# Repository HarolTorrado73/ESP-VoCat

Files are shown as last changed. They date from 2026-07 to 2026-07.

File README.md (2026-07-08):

# ESP-VoCat Smart Rotating Base

[Español](README_ES.md) | English

> **Spanish technical documentation:** [README_ES.md](README_ES.md) · [docs/es/](docs/es/)

## Project Overview

The ESP-VoCat rotating base is a smart rotating platform designed specifically for the [**ESP-VoCat development kit**](https://docs.espressif.com/projects/esp-dev-kits/zh_CN/latest/esp32s3/esp-vocat/user_guide_v1.2.html), tailored for toys, smart speakers, smart hubs, and other products requiring large language model voice interaction capabilities. The device uses the ESP32-C61-WROOM-1 module, supports USB Type-C power supply, and can power the ESP-VoCat main unit through a magnetic interface.

This project implements **high-precision stepper motor control, magnetic slide switch event detection, CSI sensing capabilities**, and stable **UART communication** as core functions. It can automatically adjust direction based on ESP-VoCat's **Sound Source Localization** results, enabling intelligent rotation toward sound sources. By combining motion control with sound source perception, it provides a more **natural and immersive** human-computer interaction experience.

## Key Features

- **Precise Angle Control** - High-precision rotational positioning based on stepper motor
- **Magnetic Slide Switch** - Multiple sensor support with automatic calibration
- **Rich Preset Actions** - Natural movements like shake head, look around, beat rhythm
- **Auto Homing** - Automatic zero position finding and calibration on startup
- **Bidirectional Communication** - Real-time data exchange between controller and base
- **Data Persistence** - Calibration data saved, survives power loss

## Project Structure

```
esp-vocat-base/
├── hardware/                    # Hardware design files
│   ├── schematics/              # Schematics
│   └── pcb/                     # PCB design files
├── software/                    # Firmware code
│   ├── common_components/       # Shared components for all examples
│   │   ├── stepper_motor/               # Stepper motor control
│   │   ├── magnetic_slide_switch/       # Magnetic switch (profile-based)
│   │   ├── control_serial/              # Serial communication
│   │   └── BMM150_SensorAPI/            # Sensor driver
│   ├── esp_vocat_rotating_base/                         # Base firmware
│   ├── esp_vocat_rotating_base_bell_event_detection/    # Bell slider event demo
│   ├── esp_vocat_rotating_base_iphone_detection/        # iPhone detection demo
│   └── esp_vocat_rotating_base_magnetic_accessory_detection/ # Accessory detection demo
├── README_ES.md                 # Spanish documentation
└── README.md                    # English documentation (this file)
```

## Example Projects

To avoid frequent branch switching, `software/` includes 4 independently buildable example projects:

- `esp_vocat_rotating_base`  
  Base firmware with standard capabilities: stepper actions, core magnetic slider events, UART communication, calibration, and status sync.

- `esp_vocat_rotating_base_bell_event_detection`  
  Bell slider event detection demo, focused on bell-related magnetic slider event logic.

- `esp_vocat_rotating_base_iphone_detection`  
  iPhone detection demo, focused on phone approach/leave and under-base related detection events.

- `esp_vocat_rotating_base_magnetic_accessory_detection`  
  Magnetic accessory detection demo, focused on accessory magnetic event recognition (e.g. fish/ice-cream/donut style accessories).

All projects share common components under `software/common_components/`.  
The `magnetic_slide_switch` component selects different profiles per project to keep event definitions and detection behavior compatible.

## **Feature Showcase**

[**Video Showcase**](https://www.bilibili.com/video/BV19gSEBwEoj/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)

The ESP-VoCat base uses Espressif's **ESP32-C61-WROOM-1(N8R2)** module and communicates with the ESP-VoCat main unit via a custom UART protocol. In terms of mechanical structure, the base is equipped with a 24BYJ48 stepper motor, enabling sound source localization and various predefined rotation actions to enhance interaction experience.
Additionally, the ESP-VoCat base features a magnetic slide switch that unlocks more interactive experiences.

### **Sound Source Localization**
ESP-VoCat supports sound source localization, capable of real-time detection of sound direction and position in the environment. The system collects sound signals through a microphone array and analyzes sound intensity, phase, and other information to determine the azimuth of the sound source. Combined with an ultra-quiet stepper motor-based rotating base, it enables intelligent interaction facing the sound source.

Sound Source Localization

### **Multiple Preset Actions**
The rotating base supports various predefined actions:

- **Shake Head Action**
The shake head action makes the base gently swing the companion left and right, simulating a cat's curious or subtle gesture.

Shake Head

- **Curious Look Around**
The curious look around action makes the base move the companion's head left and right, with small random offsets, simulating a **cat naturally observing its environment**.

Look Around

- **Beat Rhythm**
The beat rhythm action enables ESP-VoCat to swing its head left and right according to **drum beats** in external music, creating an **interactive effect** synchronized with music.

Beat Following

- **Gentle Nuzzle**
The gentle nuzzle simulates a cat's tender nuzzling action: the base slowly turns left and returns to center, repeating several times. The motion is smooth and natural, with each pause enhancing the **tactile feel** and **gentleness**.

Nuzzle

  **Notes:**
  All actions are **parametrically controllable**, facilitating integration with large models like **Doubao** and **Xiaozhi**.
  To better execute actions, the base's motor control features:
  - **Precise Angle Control:** Supports rotation at any angle with precision up to 0.1 degrees, serving sound source localization
  - **Smooth Acceleration/Deceleration:** Uses acceleration algorithms for natural and smooth rotation
  - **Auto Homing Calibration:** 
  Since the ESP-VoCat rotating base is driven by a stepper motor, it has no angle feedback. Therefore, the base performs zero position calibration at startup:
   1. After power-on, the motor automatically rotates left to find the limit switch
   2. After touching the limit switch, the motor rotates right 95° to the center position
   3. After calibration is complete, the motor powers off

### **Magnetic Slide Switch Interaction Control**
The ESP-VoCat base implements multiple interaction controls through a **magnetic** slide switch. Different slider positions change the magnetic field strength around the magnetometer. The base identifies slider actions by monitoring these magnetic field changes in real-time. When position changes are detected, the base reports corresponding events to ESP-VoCat via serial port, enabling rich and intuitive interactive experiences.

Supports 9 types of magnetic slide switch event detection:
   - Slider moved from up to down (`SLIDE_DOWN`): Slider is moved from the upper position to the lower position.
   - Slider moved from down to up (`SLIDE_UP`): Slider is moved from the lower position to the upper position.
   - Slider removed from up position (`REMOVE_FROM_UP`): Slider is removed from the upper position.
   - Slider removed from down position (`REMOVE_FROM_DOWN`): Slider is removed from the lower position.
   - Slider placed at up position (`PLACE_FROM_UP`): Slider is placed into the upper position.
   - Slider placed at down position (`PLACE_FROM_DOWN`): Slider is placed into the lower position.
   - Single click action (`SINGLE_CLICK`): A single-click action is detected when the slider stays at the lower position.
   - Fish feeding event (`FISH_ATTACHED`): Fish accessory is detected as attached.
   - Pairing mode (`PAIRING`): Two ESP-VoCat devices are face-to-face and pairing condition is detected.

Magnetic Switch

Magnetic slide switch control supports **multiple sensors**:
 - BMM150 3-axis magnetometer
 - QMC6309 3-axis magnetometer
 - Linear Hall sensor

  **Notes:**
  1. **Choose one** of the above sensors; **BMM150** is selected by default. When using a linear Hall sensor, **only** slider up/down sliding (SLIDE_UP / SLIDE_DOWN) event detection is supported!
  2. Before first use, **fully automatic calibration** of the magnetic slide switch is required to adapt to the magnetic environment, recording magnetic field strength baseline values for three states: **up / down / removed**:
     - System automatically detects three stable positions (keep still for about 500ms each position)
     - No manual prompts required, system automatically judges position differences
     - Calibration data persistently stored via NVS Flash, survives power loss
     - During use, recalibration can be triggered by sending a serial command from ESP-VoCat or long-pressing the base's Boot button

Based on magnetometer detection results combined with intelligent motion determination algorithms, the base can recognize nine types of actions and events.

### **CSI Sensing Capability**
The companion can perceive environmental changes through Wi-Fi CSI (Channel State Information), enabling action triggering or environmental interaction.
- **Movement Detection** 
By obtaining CSI information from routers through the companion, human movement throughout the entire space can be detected, enabling human movement detection and data statistics.

- **Near-field Perception** 
Through packet exchange between the companion and base, Wi-Fi transmission paths can be controlled to achieve small-range, high-precision detection. For example, when a human finger is detected approaching, the base can automatically adjust posture or execute preset actions, enabling smarter interactive experiences.

CSI Sensing

### **Serial Communication**
The ESP-VoCat rotating base communicates with ESP-VoCat via **UART protocol**.

- **Command Types**:
    - Angle control command (CMD_BASE_ANGLE_CONTROL)
    - Preset action control command (CMD_BASE_ACTION_CONTROL)
    - Preset action completion notification (CMD_ACTION_COMPLETE)
    - Magnetic switch event report (CMD_MAGNETIC_SWITCH_EVENT)
    - Magnetic data calibration progress sync (MAG_SWITCH_CALIB_*)

Note: Currently only the above basic command types are available; CSI-related commands will be added later.
    
-  **Data Frame Format**:
    -   `AA 55 [LEN_H] [LEN_L] [CMD] [DATA...] [CHECKSUM]` 
-  **Verification Mechanism**:
    - **Frame header** verification
    - **Checksum** verification

[**Detailed command data frame example**](software/esp_vocat_rotating_base/README.md)

## **Hardware Requirements**

### **Main Control Chip**
- **ESP32-C61-WROOM-1** or **ESP32-C61-WROOM-1U** module

ESP32-C61-WROOM-1 is used by default

- [**Hardware Open Source**](https://oshwhub.com/esp-college/esp-echoear-base)

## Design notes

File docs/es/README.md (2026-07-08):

# Documentación técnica en español

Índice de la documentación del proyecto ESP-VoCat Base.

[← Guía central del proyecto](../README_ES.md)

| Documento | Descripción |
|---|---|
| [arquitectura.md](arquitectura.md) | Diagramas Mermaid: sistema, capas, UART, calibración, estados |
| [hardware.md](hardware.md) | **Hardware completo:** Main/Sub Board, análisis esquemático, GPIO, motor, sensores |
| [BOM.md](BOM.md) | **Lista de materiales** — designadores, valores, MPN, alternativas |
| [lista-compra.md](lista-compra.md) | **Lista de compra** por categorías + Espressif vs equivalentes |
| [guia-ensamblaje.md](guia-ensamblaje.md) | **Guía de fabricación** — impresión 3D, ensamblaje, calibración |
| [auditoria-hardware.md](auditoria-hardware.md) | **Auditoría hardware** — MPN, contradicciones, checklist, reproducibilidad |
| [auditoria-documentacion.md](auditoria-documentacion.md) | **Auditoría docs** — archivos chinos, plan de limpieza |
| [tablas-referencia.md](tablas-referencia.md) | GPIO, hardware, sensores, UART, eventos, proyectos |
| [arranque-firmware.md](arranque-firmware.md) | Secuencia de boot + diagramas de secuencia |
| [perfiles.md](perfiles.md) | Arquitectura `MAG_SW_PROFILE` y diferencias entre demos |
| [extender-proyecto.md](extender-proyecto.md) | Nuevo perfil, sensor, acción; buenas prácticas |
| [troubleshooting.md](troubleshooting.md) | Resolución de problemas frecuentes |

## Firmware por proyecto

- [esp_vocat_rotating_base](../software/esp_vocat_rotating_base/README_ES.md) — perfil `base`
- [bell_event_detection](../software/esp_vocat_rotating_base_bell_event_detection/README_ES.md) — perfil `bell`
- [iphone_detection](../software/esp_vocat_rotating_base_iphone_detection/README_ES.md) — perfil `iphone`
- [magnetic_accessory_detection](../software/esp_vocat_rotating_base_magnetic_accessory_detection/README_ES.md) — perfil `magnetic_accessory`

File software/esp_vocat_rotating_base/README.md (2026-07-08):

# ESP-VoCat Rotating Base

[Español](README_ES.md) | **English**

## Project Introduction

This project is the firmware for the rotating base of Espressif's ESP-VoCat intelligent interactive device, developed based on the ESP32-C61 chip. The project implements precise stepper motor control, magnetic slide switch detection, UART communication, and other features, providing vivid interactive actions and sensitive input detection for smart devices.

## Main Features

### Stepper Motor Control
- **Multiple Predefined Actions**:
  - Head shaking action (fixed amplitude/gradual decay)
  - Look around observation action
  - Cat nuzzle action
  - Beat swing action following rhythm

All actions are parameterizable for easy integration with LLMs like Doubao and Xiaozhi.
- **Precise Angle Control**: Supports arbitrary angle rotation with precision up to 0.1 degrees
- **Smooth Acceleration/Deceleration**: Uses acceleration/deceleration algorithms for more natural and fluid motion
- **Half-Step Drive Mode**: Doubles precision for smoother movement
- **Auto Homing Calibration**: Automatically returns to zero position via limit switch on startup

### Magnetic Slide Switch
- **Multiple Sensor Support**:
  - BMM150 3-axis magnetometer
  - QMC6309 3-axis magnetometer
  - Linear Hall sensor

Choose one of the above three sensors, BMM150 is selected by default.
- **Rich Event Detection**:
  - Slider up/down sliding (SLIDE_UP / SLIDE_DOWN)
  - Remove from up/down position (REMOVE_FROM_UP / REMOVE_FROM_DOWN)
  - Place back from up/down position (PLACE_FROM_UP / PLACE_FROM_DOWN)
  - Single click event (SINGLE_CLICK): Detected based on mag_x axis data changes, combined with mag_x and mag_y relationship judgment to prevent false triggers from sliding
  - Fish feeding event (FISH_ATTACHED): Detects specific magnetic field changes when small fish is placed from up position
  - Pairing mode (PAIRING): Two ESP-VoCat devices face-to-face for pairing and networking
- **Smart Calibration Function**:
  - Fully automatic calibration process: No manual prompts required, system automatically detects three stable positions
  - Fast stability detection: 500ms stability time for both BMM150 and QMC6309
  - Intelligent position recognition: Automatically judges position differences to avoid duplicate recording
  - Calibration data persistent storage (NVS Flash)
  - Support UART command triggered recalibration
  - Support long press Boot button triggered recalibration
  - Auto-adapt to different magnetic field environments

### UART Communication
- **UART Protocol Communication**: Data communication with ESP-VoCat
- **Command Types**:
  - Angle control command (CMD_BASE_ANGLE_CONTROL)
  - Preset action control command (CMD_BASE_ACTION_CONTROL)
  - Preset action completion notification (CMD_ACTION_COMPLETE)
  - Magnetic switch event reporting (CMD_MAGNETIC_SWITCH_EVENT)
  - Calibration progress notification (MAG_SWITCH_CALIB_*)
- **Data Frame Format**: `AA 55 [LEN_H] [LEN_L] [CMD] [DATA...] [CHECKSUM]`
- **Verification Mechanism**: Supports **frame header** verification and **checksum** validation

## Hardware Requirements

### Main Control Chip
- **ESP32-C61-WROOM-1** or **ESP32-C61-WROOM-1U** module

ESP32-C61-WROOM-1 is used by default

### Peripheral Connection and Pin Assignment

#### Stepper Motor (28BYJ-48 + ULN2003 Driver IC)
- IN1 → GPIO28
- IN2 → GPIO27
- IN3 → GPIO26
- IN4 → GPIO25

#### Magnetometer Sensor (I2C)
- SCL → GPIO3
- SDA → GPIO2
- Supports BMM150 (I2C address: 0x10)
- Supports QMC6309 (I2C address: 0x7C)

#### Linear Hall Sensor (ADC)
- ADC_PIN → GPIO5 (ADC_CHANNEL_3)

#### Turntable Homing Calibration Limit Switch
- Homing calibration limit switch detection pin → GPIO1 (active low)

#### BOOT Button
- BOOT button → GPIO9 (active low)

Used by default for long press to trigger magnetic slide switch calibration.

#### UART Communication
- TXD → GPIO29
- RXD → GPIO8
- Baud rate: 115200

## Software Architecture

### Main Components

#### 1. stepper_motor (Stepper Motor Control)
- Implements half-step drive control algorithm
- Provides acceleration/deceleration curves
- Encapsulates multiple predefined actions
- Supports precise angle rotation

#### 2. magnetic_slide_switch (Magnetic Slide Switch)
- Sliding window filtering algorithm (mag_z axis)
- State machine implements event detection
- Single click detection (based on mag_x axis change + mag_x/mag_y relationship judgment)
- Fish feeding event detection (specific magnetic field increment range)
- Pairing mode detection (two ESP-VoCat face-to-face for pairing)
- Fully automatic calibration process (time-based + intelligent position recognition)
- Calibration data NVS persistent storage

#### 3. control_serial (UART Communication)
- UART TX/RX tasks
- Protocol frame parsing
- Command dispatch processing
- Event reporting

#### 4. BMM150_SensorAPI (Sensor Driver)
- BMM150 official API adaptation
- I2C bus encapsulation

### Task Structure
```
app_main
├── base_calibration_task          // Base angle calibration task (on startup)
├── uart_cmd_receive_task          // UART command receive task
├── uart_cmd_send_task             // UART command send task
├── magnetometer_data_read_task    // Magnetometer data read task (shared data source)
├── magnetometer_calibration_task  // Magnetic switch automatic calibration task
└── slide_switch_event_detect_task // Magnetic slide switch event detection task
```

## Quick Start

### Environment Preparation

1. **ESP-IDF Version**

- ESP-IDF release/v5.5(v5.5-445-g1191f4c4f91-dirty)

### Project Configuration

Use `idf.py menuconfig` to select the sensor for the magnetic slide switch:

 `Component config → Magnetic Slide Switch → Sensor Type`

Select sensor type: BMM150 / QMC6309 / Linear Hall Sensor

### Build and Flash

```bash
# Build project
idf.py build
# Flash firmware
idf.py flash
# View logs
idf.py monitor
```

## Usage Instructions

### First Startup

1. **Base Angle Calibration**:
   - After power-on, the motor will automatically rotate left to find the limit switch
   - After touching the limit switch, the motor will rotate right 95° to the center position
   - After calibration is complete, the motor powers off

2. **Magnetic Switch Automatic Calibration** (if first use):
   - System automatically detects the first stable position (keep slider still for about 500ms)
   - After the system records the first position, prompt: `First position calibrated`
   - Move the slider to a second different position (up/down/removed), system automatically detects stability
   - After the system records the second position, send `0x12` to ESP-VoCat to notify second position calibration complete
   - Move the slider to a third different position, system automatically detects stability
   - After the system records the third position, automatically sort by magnetic field strength and assign to REMOVED/UP/DOWN
   - After calibration is complete, send `0x13` to ESP-VoCat to notify calibration complete
   - Calibration data is automatically saved to Flash, automatically loaded on next startup
   
   **Note**:
   - Each position needs to be kept still for system to automatically detect stability (about 500ms)
   - The magnetic field difference between three positions must be greater than 100 (system automatically judges)
   - Data changes during movement are normal, system will automatically wait for stability before recording

### Recalibration

**Method 1: Long Press Boot Button**
- Long press the Boot button on GPIO9 (about 1.5 seconds)
- System automatically enters recalibration mode

**Method 2: UART Command**
- Send command: `AA 55 00 03 03 00 10 16`
- System enters recalibration mode after receiving the command

### UART Commands

#### 1. Magnetic Attachment Notification Command（0x00）
`
AA 55 00 03 00 00 01 01
`

The base periodically sends this command. Once ESP-VoCat is magnetically attached and successfully receives the command, it can confirm that the connection to the base has been established and then start playing the connection animation.

#### 2. Angle Control Command (0x01)
**Format**: `AA 55 00 03 01 [ANGLE_H] [ANGLE_L] [CHECKSUM]`

**Example**: Rotate to 45°
```
AA 55 00 03 01 00 2D 2E
```
- `00 2D` = 45 (decimal)
- `2E` = `01 + 00 + 2D` (checksum)

#### 3. Action Control Command (0x02)
**Format**: `AA 55 00 03 02 00 [ACTION] [CHECKSUM]`

**Action Codes**:
- `0x01`: Shake head (SHAKE_HEAD)
- `0x02`: Look around (LOOK_AROUND)
- `0x03`: Beat swing - drum (BEAT_SWING_DRUM)
- `0x04`: Cat nuzzle (CAT_NUZZLE)
- `0x05`: Beat swing - other instruments (BEAT_SWING_OTHER)

**Example**: Execute look around action
```
AA 55 00 03 02 00 02 04
```

#### 4. Magnetic Switch Event Reporting (0x03)
**Format**: `AA 55 00 03 03 00 [EVENT] [CHECKSUM]`

**Event Codes**:
- `0x01`: Slider slides down (SLIDE_DOWN)
- `0x02`: Slider slides up (SLIDE_UP)
- `0x03`: Remove from top (REMOVE_FROM_UP)
- `0x04`: Remove from bottom (REMOVE_FROM_DOWN)
- `0x05`: Place back from top (PLACE_FROM_UP)
- `0x06`: Place back from bottom (PLACE_FROM_DOWN)
- `0x07`: Single click event (SINGLE_CLICK)
- `0x08`: Fish feeding event (FISH_ATTACHED) - Triggered when small fish is placed from up position
- `0x09`: Pairing mode (PAIRING) - Two ESP-VoCat face-to-face for pairing
- `0x10`: Start calibration program
- `0x11`: Calibration start notification
- `0x12`: Second position calibration complete (ESP-VoCat gives voice prompt for third step after receiving)
- `0x13`: Calibration complete

#### 5. Action Completion Notification (0x02)
**Format**: `AA 55 00 03 02 00 10 12`

- Base automatically sends after completing any specific action
- ESP-VoCat can synchronize status according to this command

## Stepper Motor Action Details

### 1. stepper_shake_head (Shake Head)
```c
stepper_shake_head(float amplitude, int cycles, int speed_us);
```
- `amplitude`: Swing amplitude (degrees)
- `cycles`: Number of swings
- `speed_us`: Speed (microseconds/step)

### 2. stepper_shake_head_decay (Gradual Decay Shake Head)
```c
stepper_shake_head_decay(float initial_amplitude, float decay_rate, int speed_us);
```
- `initial_amplitude`: Initial amplitude (degrees)
- `decay_rate`: Decay coefficient (0.0-1.0, e.g., 0.8 means 20% decay each time)
- `speed_us`: Speed (microseconds/step)

### 3. stepper_look_around (Look Around)
```c
stepper_look_around(float left_angle, float right_angle, float scan_angle, 
                    int pause_ms, int large_speed_us, int small_speed_us);
```
- `left_angle`: Maximum left angle
- `right_angle`: Maximum right angle
- `scan_angle`: Small amplitude scan angle
- `pause_ms`: Pause time after each rotation
- `large_speed_us`: Large amplitude rotation speed
- `small_speed_us`: Small amplitude scan speed

### 4. stepper_cat_nuzzle (Cat Nuzzle)
```c
stepper_cat_nuzzle(float angle, int cycles, int speed_us);
```
- `angle`: Nuzzle amplitude (degrees)
- `cycles`: Number of nuzzles
- `speed_us`: Speed (microseconds/step)

### 5. stepper_beat_swing (Beat Swing)
```c
stepper_beat_swing(float angle, int speed_us);
```
- `angle`: Swing angle (degrees)
- `speed_us`: Speed (microseconds/step)
- **Smart Swing Logic**:
  - Same instrument type continuously triggered → Swing 15 degrees to the other side

## Magnetic Switch Calibration Principle

### Automatic Calibration Flow State Machine

```
CALIBRATION_DETECTING_FIRST      // Automatically detect first stable position
         ↓                       // Record automatically after data stable for 500ms
CALIBRATION_WAITING_CHANGE_1     // Wait for data change (user moves slider)
         ↓                       // Change amount detected > 100
CALIBRATION_DETECTING_SECOND     // Automatically detect second stable position
         ↓                       // Record automatically after data stable for 500ms
         |                       // (Send 0x12 to notify ESP-VoCat)
CALIBRATION_WAITING_CHANGE_2     // Wait for data change (user moves slider)
         ↓                       // Change amount detected > 100
CALIBRATION_DETECTING_THIRD      // Automatically detect third stable position
         ↓                       // Record automatically after data stable for 500ms
CALIBRATION_COMPLETED            // Auto sort and save to Flash
                                 // (Send 0x13 to notify ESP-VoCat)
```

### Key Technical Points

1. **Sliding Window Filtering**: 5-point moving average to reduce noise interference
2. **Time-based Stability Detection**:
   - Uses system clock (FreeRTOS Tick) for precise timing
   - Data change less than 10 units considered stable
   - Both BMM150 and QMC6309: Record after continuous stability for 500ms
3. **Intelligent Position Recognition**:
   - Automatically detects data change amount (threshold 100)
   - New position must be significantly different from recorded positions
   - Prevents duplicate recording of same position
4. **Automatic Sorting and Assignment**:
   - Sort by magnetic field strength from small to large
   - Smallest value → REMOVED (removed)
   - Middle value → UP (up position)
   - Largest value → DOWN (down position)
5. **NVS Persistence**: Calibration data saved to Flash, not lost after power off
6. **No Manual Prompts Required**: Fully automatic detection, users only need to move slider in sequence and keep still

### Magnetic Field Value Reference Range (BMM150)
- **REMOVED** (removed): ~700-800 (default 709)
- **UP** (up position): ~1300-1400 (default 1383)
- **DOWN** (down position): ~2000-2100 (default 2047)
- **FISH_ATTACHED** (fish feeding): REMOVED + 150~200

*Note: Actual values vary due to magnet strength and installation position, automatic calibration will assign positions based on actual magnetic field*

### Event Detection Features

**Single Click Event Detection**:
- Based on mag_x axis data change (drop/rise threshold: 100)
- Combined with mag_x and mag_y size relationship to judge slider position
- Only detected when slider is at DOWN position (mag_x > mag_y)
- Duration filtering: < 300ms for valid click
- Prevents false triggers from fast sliding

**Fish Feeding Event Detection**:
- Only detected after REMOVED position
- Magnetic field increment in 150-200 range
- Distinguished from PLACE_FROM_UP (larger increment, close to UP_CENTER)

**Pairing Mode Detection**:
- Magnetic field continues to drop after REMOVED position
- Drop amount > 100 (BMM150) / 150 (QMC6309)
- Stably maintains this state

### Common Issues

**Q1: Motor vibrates or doesn't rotate**
- Check if power supply is sufficient (at least 5V 1A)
- Check if wiring is correct
- Try reducing speed (increase `speed_us` parameter)

**Q2: Magnetic switch calibration fails**
- Ensure sensor I2C connection is normal
- Check if sensor type configuration matches
- Each position needs to be kept still for at least 500ms (both BMM150 and QMC6309)
- The magnetic field difference between three positions must be greater than 100, ensure positions are clearly different
- If movement is too fast causing detection failure, wait a moment for system to re-detect

**Q3: Single click event false trigger or not triggered**
- False trigger: May be caused by fast sliding, system has been optimized through mag_x/mag_y relationship
- Not triggered: Ensure slider is at DOWN position (mag_x > mag_y), click action should be clear and fast
- Click duration should be less than 300ms, too slow will be recognized as sliding

**Q4: UART communication abnormal**
- Check if baud rate is 115200
- Confirm TX/RX wiring is correct
- Check if checksum is calculated correctly

**Q5: Motor rotates in wrong direction on first power-on**
- Check limit switch installation position
- Adjust rotation angle in `base_calibration_task`

## Performance Parameters

- **Angle Control Precision**: ±0.5°
- **Fastest Rotation Speed**: 600 μs/step (about 200°/second)
- **Magnetic Switch Response Time**: < 50ms
- **Magnetic Switch Sampling Rate**: 100 Hz (BMM150, 10ms period) / 500 Hz (QMC6309, 2ms period)
- **Calibration Stability Detection Time**: 500ms (both BMM150 and QMC6309)
- **Single Click Detection Time Window**: < 300ms (BMM150) / < 250ms (QMC6309)
- **UART Communication Rate**: 115200 bps
- **Memory Usage**: ~80KB RAM, ~200KB Flash

## Version History

### v1.1.0
- **New Features**:
  - Fish feeding event detection (FISH_ATTACHED)
  - Pairing mode detection (PAIRING)
- **Optimizations**:
  - Fully automatic magnetic data calibration process (no manual prompts required)
  - Time-based stability detection (FreeRTOS Tick timing)
  - Single click event detection optimization: Based on mag_x axis + mag_x/mag_y relationship judgment
  - Prevents false single click triggers from fast sliding
  - Calibration stability time optimization: Both BMM150 and QMC6309 reduced to 500ms
  - Intelligent position recognition (automatically judges position differences)

### v1.0.0
- Stepper motor basic control
- Multiple predefined actions
- Magnetic slide switch event detection
- Auto calibration function
- NVS data persistence
- UART communication protocol
- Smart beat following algorithm
- Long press Boot button recalibration
- Calibration process UART communication

## License

This project follows the GPL 3.0 license.

---

**Note**: This project is supporting firmware for Espressif's ESP-VoCat smart device, for learning and reference only.

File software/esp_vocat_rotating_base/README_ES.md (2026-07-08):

# ESP-VoCat Base: Firmware estándar

**[Español](README_ES.md)** | [English](README.md)

> **Perfil:** `base` · **Versión:** V1.0.4  
> **Documentación completa:** [Guía central del proyecto](../../README_ES.md)

---

## Descripción

Firmware principal de la base rotatoria ESP-VoCat. Implementa control del motor paso a paso, detección magnética con perfil `base`, comunicación UART y calibración automática.

**Diferencia clave respecto a los demos:** en este proyecto los eventos magnéticos se envían por UART **directamente** desde `magnetic_slide_switch.c` (sin callback en `app_main`).

---

## Eventos soportados (perfil `base`)

| Código | Evento |
|---|---|
| 1–7 | Deslizamiento, colocación, retirada, clic simple |
| 8–9 | Pez adherido / retirado |
| 10–11 | Emparejamiento / cancelado |

Tabla completa: [Tablas de referencia → Eventos](../../docs/es/tablas-referencia.md#perfil-base-esp_vocat_rotating_base)

---

## Compilar

```bash
cd software/esp_vocat_rotating_base
idf.py set-target esp32c61
idf.py menuconfig    # Magnetic Slide Switch → Sensor Type
idf.py build flash monitor
```

---

## Documentación relacionada

| Tema | Enlace |
|---|---|
| GPIO, UART, acciones | [Tablas de referencia](../../docs/es/tablas-referencia.md) |
| Arranque y secuencias | [Arranque del firmware](../../docs/es/arranque-firmware.md) |
| Arquitectura | [Arquitectura del sistema](../../docs/es/arquitectura.md) |
| Comandos UART detallados | [Tablas → UART](../../docs/es/tablas-referencia.md#comandos-uart) |
| Calibración magnética | [Arquitectura → Calibración](../../docs/es/arquitectura.md#5-flujo-de-calibración-automática-magnética) |
| Problemas frecuentes | [Troubleshooting](../../docs/es/troubleshooting.md) |

---

## Tareas FreeRTOS de esta aplicación

```
app_main
├── base_calibration_task          # Homing mecánico (GPIO 1 → +95°)
├── uart_cmd_receive_task          # Comandos UART (prioridad 12)
├── magnetic_detect_task           # Acoplamiento magnético cada 500 ms
├── mag_data_read_task             # Lectura sensor I2C
├── mag_calibration_task           # Calibración automática 3 posiciones
└── slide_switch_event_detect_task # Detección de eventos → UART directo
```

---

## Licencia

GPL-3.0 — Firmware de referencia para el kit ESP-VoCat de Espressif.

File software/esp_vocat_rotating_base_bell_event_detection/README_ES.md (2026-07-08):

# ESP-VoCat Base: Detección de eventos de campana

**[Español](README_ES.md)** | [English](README.md)

> **Perfil:** `bell` · **Versión:** V1.0.4  
> **Documentación completa:** [Guía central del proyecto](../../README_ES.md)

---

## Descripción

Demostración centrada en el **deslizador tipo campana**. Utiliza el perfil `magnetic_slide_switch/profiles/bell` y registra un callback en `app_main` que reenvía los eventos detectados a ESP-VoCat por UART.

```c
// esp_vocat_rotating_base_main.c
magnetic_slide_switch_register_callback(magnetic_slide_switch_event_cb);
```

---

## Eventos soportados (perfil `bell`)

| Código | Evento |
|---|---|
| 1 | `SLIDE_DOWN` |
| 2 | `SLIDE_UP` |
| 3 | `REMOVE_FROM_UP` |
| 4 | `REMOVE_FROM_DOWN` |
| 5 | `PLACE_FROM_UP` |
| 6 | `PLACE_FROM_DOWN` |
| 7 | `SINGLE_CLICK` |

No incluye eventos de pez, emparejamiento, iPhone ni accesorios.

Detalle: [Sensado magnético → Campana](../../magnetic_sensing_interaction_solution_es.md#21-demostración-de-eventos-del-deslizador-tipo-campana)

---

## Compilar

```bash
cd software/esp_vocat_rotating_base_bell_event_detection
idf.py set-target esp32c61
idf.py build flash monitor
```

`CMakeLists.txt` define `set(MAG_SW_PROFILE "bell")`.

---

## Diferencias respecto al firmware base

| Aspecto | `base` | `bell` (este proyecto) |
|---|---|---|
| Perfil CMake | `base` | `bell` |
| Eventos | 1–11 | 1–7 |
| Reporte UART | Directo en componente | Callback en `app_main` |
| Pez / emparejamiento | Sí | No |

Comparativa completa: [Perfiles](../../docs/es/perfiles.md#diferencias-entre-perfiles)

---

## Documentación relacionada

| Tema | Enlace |
|---|---|
| Arquitectura de perfiles | [docs/es/perfiles.md](../../docs/es/perfiles.md) |
| Tablas GPIO / UART | [docs/es/tablas-referencia.md](../../docs/es/tablas-referencia.md) |
| Troubleshooting | [docs/es/troubleshooting.md](../../docs/es/troubleshooting.md) |

---

## Licencia

GPL-3.0

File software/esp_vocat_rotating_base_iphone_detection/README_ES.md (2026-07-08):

# ESP-VoCat Base: Detección de iPhone

**[Español](README_ES.md)** | [English](README.md)

> **Perfil:** `iphone` · **Versión:** V1.0.4  
> **Documentación completa:** [Guía central del proyecto](../../README_ES.md)

---

## Descripción

Demostración de **detección de proximidad de iPhone** mediante variaciones del eje Z del magnetómetro respecto a la línea base calibrada. Usa el perfil `magnetic_slide_switch/profiles/iphone`.

Los eventos se reportan vía callback registrado en `app_main` → `control_serial_send_magnetic_switch_event()`.

---

## Eventos soportados (perfil `iphone`)

| Código | Evento | Criterio (BMM150) |
|---|---|---|
| 16 | `IPHONE_LEAN_FRONT` | ΔZ ≥ 450 respecto a baseline |
| 17 | `IPHONE_LEAN_FRONT_DETACHED` | iPhone se separa del frente |
| 18 | `IPHONE_UNDER_BASE` | Caída de Z ≥ 600 (bajo la base) |
| 19 | `IPHONE_UNDER_BASE_DETACHED` | iPhone retirado de debajo |

Umbrales definidos en `profiles/iphone/include/magnetic_slide_switch.h` (`MAGNETIC_ACCESSORY_DETECTION_Z_INCREASE`, `MAGNETIC_ACCESSORY_DETECTION_Z_DROP_UNDER_BASE`).

Detalle: [Sensado magnético → iPhone](../../magnetic_sensing_interaction_solution_es.md#22-demostración-de-detección-de-iphone)

---

## Compilar

```bash
cd software/esp_vocat_rotating_base_iphone_detection
idf.py set-target esp32c61
idf.py build flash monitor
```

`CMakeLists.txt` define `set(MAG_SW_PROFILE "iphone")`.

---

## Diferencias respecto al firmware base

| Aspecto | `base` | `iphone` (este proyecto) |
|---|---|---|
| Eventos de deslizador | Sí (1–7) | No |
| Eventos iPhone | No | Sí (16–19) |
| Lógica de detección | Eje Z + estados UP/DOWN | Variación ΔZ vs baseline |

---

## Documentación relacionada

| Tema | Enlace |
|---|---|
| Perfiles | [docs/es/perfiles.md](../../docs/es/perfiles.md) |
| Calibración | [docs/es/arranque-firmware.md](../../docs/es/arranque-firmware.md) |
| Troubleshooting | [docs/es/troubleshooting.md](../../docs/es/troubleshooting.md) |

---

## Licencia

GPL-3.0

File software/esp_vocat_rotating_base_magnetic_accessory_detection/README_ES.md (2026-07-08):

# ESP-VoCat Base: Detección de accesorios magnéticos

**[Español](README_ES.md)** | [English](README.md)

> **Perfil:** `magnetic_accessory` · **Versión:** V1.0.4  
> **Documentación completa:** [Guía central del proyecto](../../README_ES.md)

---

## Descripción

Demostración de **accesorios magnéticos** (pez, helado, dona) y modo emparejamiento. Usa el perfil `magnetic_slide_switch/profiles/magnetic_accessory` con detección basada en incrementos del eje Z respecto a la posición `REMOVED` calibrada.

Incluye **baseline dinámico** (EMA) y **confirmación retardada** (`ACCESSORY_CONFIRM_MS = 200 ms`) para distinguir accesorios.

---

## Eventos soportados (perfil `magnetic_accessory`)

| Código | Evento |
|---|---|
| 8 | `FISH_ATTACHED` |
| 9 | `FISH_DETACHED` |
| 10 | `PAIRING` |
| 11 | `PAIRING_CANCELLED` |
| 12 | `ICE_CREAM_ATTACHED` |
| 13 | `ICE_CREAM_DETACHED` |
| 14 | `DONUT_ATTACHED` |
| 15 | `DONUT_DETACHED` |

### Rangos ΔZ (BMM150, desde `magnetic_slide_switch.h`)

| Accesorio | ΔZ mínimo | ΔZ máximo |
|---|---|---|
| Pez | 50 | 130 |
| Helado | 140 | 200 |
| Dona | 270 | 310 |

Detalle: [Sensado magnético → Accesorios](../../magnetic_sensing_interaction_solution_es.md#23-demostración-de-detección-de-accesorios-magnéticos)

---

## Compilar

```bash
cd software/esp_vocat_rotating_base_magnetic_accessory_detection
idf.py set-target esp32c61
idf.py build flash monitor
```

`CMakeLists.txt` define `set(MAG_SW_PROFILE "magnetic_accessory")`.

---

## Diferencias respecto al firmware base

| Aspecto | `base` | `magnetic_accessory` |
|---|---|---|
| Detección pez | Por deslizador (campo total) | Por ΔZ en posición REMOVED |
| Helado / dona | No | Sí |
| Baseline dinámico | No | Sí (`DYNAMIC_BASELINE_EMA_SHIFT`) |
| Confirmación retardada | No | Sí (200 ms) |

---

## Documentación relacionada

| Tema | Enlace |
|---|---|
| Perfiles y extensión | [docs/es/perfiles.md](../../docs/es/perfiles.md) |
| Tablas de eventos | [docs/es/tablas-referencia.md](../../docs/es/tablas-referencia.md) |
| Troubleshooting calibración | [docs/es/troubleshooting.md#2-el-sensor-no-calibra](../../docs/es/troubleshooting.md#2-el-sensor-no-calibra) |

---

## Licencia

GPL-3.0

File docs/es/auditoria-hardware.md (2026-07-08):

# Auditoría final de hardware — ESP-VoCat Base V1.0

> **Fecha de auditoría:** 2026-07-08  
> **Alcance:** contrastar esquemáticos PDF (`hardware/`), exportación OSHWHUB (`docs/7726, 2155.txt`), página web OSHWHUB, firmware (`software/`) y documentación de fabricación (`docs/es/`).  
> **Regla:** no se han inventado MPN ni valores no presentes en las fuentes.

[← BOM](BOM.md) · [Lista de compra](lista-compra.md) · [Guía de ensamblaje](guia-ensamblaje.md) · [Hardware](hardware.md)

---

## 1. Fuentes consultadas

| Fuente | Contenido útil | Limitaciones |
|---|---|---|
| `hardware/SCH_*MainBoard*.pdf` | Valores R/C/L, referencias IC, huellas conectoras | PDF no exporta MPN de diodos, LED ni inductor |
| `hardware/SCH_*SubBoard*.pdf` | TM-8764-1, R1/R2, pogo, CN1 | Sin MPN pogo pin |
| `docs/7726, 2155.txt` | BOM parcial (5 líneas pasivos), montaje, mecánica | Exportación web incompleta; BOM truncada |
| [OSHWHUB esp-echoear-base](https://oshwhub.com/esp-college/esp-echoear-base) (web, 2026-07-08) | Montaje, GPIO, espesor PCB, pogo orientación | Pestaña **BOM: «暂无BOM»** (sin BOM publicada) |
| `3D_models/*.stp` | Geometría 5 piezas | Sin material, orientación, relleno |
| `software/` | GPIO, homing 95°, perfil sensores | No sustituye BOM de componentes |

---

## 2. Diagrama de alimentación

```mermaid
flowchart TB
    subgraph ENTRADA["Entrada"]
        USBC["USB1<br/>TYPE-C 16PIN 2MD(073)<br/>VBUS 5 V"]
        CC["R1, R4 — 5,1 kΩ<br/>líneas CC"]
        D_USB["D1–D3<br/>MPN: no disponible en repo"]
    end

    subgraph PROTECCION["Protección / distribución 5 V"]
        D_VBUS["D6–D7<br/>MPN: no disponible en repo"]
        TPS["U3 TPS2051BDBVR<br/>límite 500 mA"]
        VBUS_RAW["VBUS 5 V<br/>motor + periféricos"]
        VBUS_OUT["VBUS_OUT<br/>→ pogo pin → host ESP-VoCat"]
    end

    subgraph REG["Regulador 3,3 V"]
        DCDC["U2 TLV62569DBVR"]
        L1["L1 — 2,2 µH<br/>MPN: requiere OSHWHUB"]
        C_BUCK["C1,C2,C7,C8<br/>10 µF / 100 nF / 22 µF"]
        V33["VCC_3V3"]
    end

    subgraph MCU["ESP32 y lógica"]
        U1["U1 ESP32-C61-WROOM-1"]
        BOOT_SW["BOOT GT-TC072A-H060-L1"]
        LED["LED1 + R8,R9 4,7 kΩ<br/>tipo LED: no disponible"]
    end

    subgraph MOTOR["Motor 5 V"]
        ULN["U4 ULN2003A"]
        M1["M1 24BYJ48<br/>5 V DC"]
        CN1["CN1 1,25-5P"]
    end

    subgraph SENSORES["Sensores 3,3 V"]
        MAG["U5 BMM150<br/>o U6 QMC6309"]
        HALL["U7 SS49E + C14,C15"]
        I2C_HDR["CN2 I2C expansión"]
    end

  subgraph SUB["Sub Board vía FFC"]
        POGO["U1 pogo 4P 2,5 mm"]
        LSW["SW1 TM-8764-1"]
    end

    USBC --> CC
    USBC --> D_USB
    USBC --> D_VBUS
    USBC --> TPS
    USBC --> VBUS_RAW
    TPS --> VBUS_OUT
    VBUS_OUT --> POGO
    VBUS_RAW --> DCDC
    VBUS_RAW --> ULN
    DCDC --> L1 --> V33
    C_BUCK --> V33
    V33 --> U1
    V33 --> MAG
    V33 --> HALL
    V33 --> I2C_HDR
    BOOT_SW --> U1
    LED --> U1
    U1 --> ULN --> CN1 --> M1
    U1 --> MAG
    U1 --> HALL
    CN3["CN3 SH1.0 5P"] --> LSW
    CN3 --> POGO
    VBUS_OUT -.-> CN3
```

**Ramas de tensión confirmadas:**

| Rail | Origen | Consumidores principales |
|---|---|---|
| **VBUS 5 V** | USB Type-C | TLV62569 (entrada), ULN2003A/motor, TPS2051B (entrada), expansión VBUS |
| **VCC_3V3** | TLV62569 + L1 2,2 µH | ESP32-C61, BMM150/QMC6309, SS49E, lógica |
| **VBUS_OUT** | TPS2051B (≤500 mA) | Host ESP-VoCat vía pogo pin |

---

## 3. Verificación R/C — esquemático vs BOM vs lista de compra

### 3.1 Condensadores (Main Board)

| Designadores | Valor (esquemático) | BOM.md | lista-compra.md | OSHWHUB | Estado |
|---|---|---|---|---|---|
| C1, C3, C8 | 10 µF | 10 µF ×3, C0603, CL10A106K | 3 × 10 µF | ID 1, CL10A106K | **Coincide** |
| C2, C4, C5, C6, C10–C14 | 100 nF | 100 nF ×9 | ~~10~~ → **9** × 100 nF (corregido) | ID 2, CL05B104K ×9 | **Coincide** (error previo en lista-compra: decía 10) |
| C9 | 1 µF | 1 µF | 1 × 1 µF | ID 3, CL05A105K | **Coincide** |
| C7 | 22 µF | 22 µF | 1 × 22 µF | No en export. parcial | **Valor coincide**; huella/MPN: no disponible |
| C15 | 10 nF | 10 nF | 1 × 10 nF | No en export. parcial | **Valor coincide**; huella/MPN: no disponible |

### 3.2 Resistencias (Main Board)

| Designadores | Valor (esquemático) | BOM.md | lista-compra.md | OSHWHUB | Estado |
|---|---|---|---|---|---|
| R1, R4 | 5,1 kΩ | 5,1 kΩ ×2 | 2 × 5,1 kΩ | No en export. | **Coincide** |
| R2 | 100 kΩ | 100 kΩ | 1 × 100 kΩ | No en export. | **Coincide** |
| R3, R6 | 10 kΩ | 10 kΩ ×2 | (incl. en 4×10 kΩ) | ID 4 parcial | **Coincide** |
| R5 | 22,1 kΩ | 22,1 kΩ | 1 × 22,1 kΩ | No en export. | **Coincide** |
| R7 | 1 kΩ | 1 kΩ | 1 × 1 kΩ | No en export. | **Coincide** |
| R8, R9 | 4,7 kΩ | 4,7 kΩ ×2 | 2 × 4,7 kΩ | ID 5 parcial | **Coincide** |
| R10, R11 | 10 kΩ | 10 kΩ ×2 | (incl. en 4×10 kΩ) | ID 4 parcial | **Coincide** |

### 3.3 Resistencias (Sub Board)

| Designadores | Valor | BOM / lista-compra | Esquemático | Estado |
|---|---|---|---|---|
| R1 | 51 kΩ | 51 kΩ | 51 kΩ | **Coincide** |
| R2 | 100 kΩ | 100 kΩ | 100 kΩ | **Coincide** |

### 3.4 Inductor

| Designador | Valor esquemático | BOM | lista-compra | MPN |
|---|---|-----|---|-----|
| L1 | 2,2 µH | Confirmado | Pendiente | **Requiere consultar OSHWHUB** (proyecto clonado en EasyEDA) |

---

## 4. Búsqueda de MPN faltantes

### 4.1 Resultado por componente

| Ref. | Tipo | Dato en esquemático PDF | Dato en OSHWHUB repo/web | MPN identificado | Conclusión |
|---|---|---|---|---|---|
| **D1–D3** | Diodos USB | Designadores junto a USB_DP/DN | Sin mención | — | **No disponible en el repositorio.** Requiere clonar proyecto EasyEDA en OSHWHUB |
| **D4–D5** | Diodos Boot | Designadores en circuito BOOT | Sin mención | — | **No disponible en el repositorio** |
| **D6–D7** | Diodos VBUS | Designadores en rama VBUS | Sin mención | — | **No disponible en el repositorio** |
| **LED1** | LED | Designador + R8/R9 4,7 kΩ | Sin mención | — | **No disponible en el repositorio** (color, encapsulado, corriente) |
| **L1** | Inductor | **2,2 µH** | Sin mención | — | Valor confirmado; **MPN y encapsulado: requiere OSHWHUB** |
| **USB1** | USB Type-C | Huella `TYPE-C 16PIN 2MD(073)` | Sin MPN | — | **Referencia de biblioteca EasyEDA**, no MPN LCSC en repo |
| **CN1** | Motor | `1.25-5P WT` | Sin MPN | — | **Referencia de huella**; requiere OSHWHUB |
| **CN2** | I2C | `HC-1.25-4PLT` | Sin MPN | — | **Referencia de huella** |
| **CN3 / CN1 Sub** | FFC | `WAFER-SHB1.0-5PLT-W1-P` | Cable SH1.0 5P 60 mm | — | Especificación mecánica confirmada; **MPN conector: requiere OSHWHUB** |
| **CN4** | RGB | `HC-1.25-3PLT` | Sin MPN | — | **Referencia de huella** |
| **H1** | LD2402 | `PZ254V-11-05P` | LD2402 listado | — | Header genérico 2,54 mm 5P; **MPN exacto: requiere OSHWHUB** |
| **U1 Sub** | Pogo pin | 4P 2,5 mm (silk) | «conector macho 4 pines 2,5 mm con oreja» | — | Especificación mecánica confirmada; **MPN: requiere OSHWHUB** |
| **SW1** | Fin de carrera | **TM-8764-1** | Sin MPN adicional | TM-8764-1 | **Referencia de componente EasyEDA** confirmada en esquemático; MPN fabricante/LCSC no verificado en repo |
| **BOOT** | Táctil | **GT-TC072A-H060-L1** | Sin MPN | GT-TC072A-H060-L1 | **Confirmado** (texto en esquemático) |
| **Rodamiento** | Mecánico | — | 7×11×3 mm | — | Dimensiones confirmadas; **MPN: requiere OSHWHUB** |

### 4.2 Estado de la BOM en OSHWHUB (verificación web 2026-07-08)

La página del proyecto muestra **«暂无BOM»** (sin BOM) en la pestaña BOM, aunque la exportación local `docs/7726, 2155.txt` conserva **5 entradas parciales** de pasivos (C y R). La BOM completa **no está accesible** sin clonar el proyecto en el editor EasyEDA de LCSC/JLCPCB.

---

## 5. Componentes confirmados

Componentes con valor, función y referencia suficiente para fabricar o sustituir con baja incertidumbre:

| Categoría | Componentes |
|---|---|
| **MCU** | ESP32-C61-WROOM-1-N8R2 |
| **IC potencia** | TLV62569DBVR, TPS2051BDBVR, ULN2003A, AO3400A |
| **Sensores** | BMM150 **o** QMC6309 (uno), SS49E |
| **Pasivos Main** | Todos los valores R1–R11; C1–C15 (valores) |
| **Pasivos Sub** | R1 51 kΩ, R2 100 kΩ |
| **Electromecánico** | BOOT GT-TC072A-H060-L1, SW1 TM-8764-1 (ref. esquemático) |
| **Motor** | 24BYJ48 DC 5V |
| **Mecánica** | Rodamiento 7×11×3 mm; tornillería M4/M2; imanes D10×1,5 y D6×5 |
| **Cable** | FFC SH1.0 5P 60 mm, doble extremo misma dirección |
| **PCB** | MainBoard + SubBoard V1.0, espesor **1,0 mm** |
| **3D** | 5 archivos STEP en `3D_models/` |
| **GPIO (firmware)** | Motor 25–28, I2C 2–3, Hall ADC 5, límite **GPIO1**, UART 8/29, Boot 9 |

---

## 6. Componentes pendientes

| Componente | Qué falta | Dónde obtenerlo |
|---|---|---|
| D1–D7 | Tipo, encapsulado, MPN | Clonar proyecto OSHWHUB → BOM EasyEDA |
| LED1 | Color, encapsulado, MPN | Idem |
| L1 | Encapsulado, corriente nominal, MPN | Idem |
| USB1, CN1–CN4, H1 | MPN LCSC/JLC | Idem |
| Pogo pin U1 Sub | MPN comercial | Idem o grupo técnico OSHWHUB |
| C7, C15 | Huella SMD exacta | Idem |
| R1,R4,R2,R5,R7 (Main) | Huella si distinta de 0402 | Idem |
| Sub Board R1,R2 | Huella | Idem |
| Rodamiento | MPN (ej. 687ZZ) | Idem / medida confirmada |
| **Gerber PCB** | Archivos de fabricación | Clonar y exportar desde OSHWHUB |
| **Parámetros impresión 3D** | Material, orientación, soportes, capa, relleno | No publicados; OSHWHUB / prueba en slicer |

---

## 7. Componentes con incertidumbre

| Tema | Detalle | Fuente en conflicto | Resolución recomendada |
|---|---|---|---|
| **Cantidad imanes D10×1,5 mm** | Montaje OSHWHUB: **2 uds.**; lista compra OSHWHUB: **1 ud.** | `7726, 2155.txt` pasos 1 vs lista materiales | Comprar **2** (coherente con montaje) |
| **Modelo motor** | Esquemático/OSHWHUB: **24BYJ48**; algunos README: **28BYJ-48** | `README_ES.md`, `tablas-referencia.md`, README firmware | Usar **24BYJ48** (esquemático + OSHWHUB + `hardware.md`) |
| **Ángulo homing** | Firmware: **95°**; OSHWHUB uso: **90°** en un apartado | `esp_vocat_rotating_base_main.c` vs web OSHWHUB | Seguir **firmware (95°)** para réplica software |
| **GPIO fin de carrera** | Firmware/OSHWHUB: **GPIO1**; `guia-ensamblaje.md` decía GPIO8 (error) | Esquemático muestra GPIO8 como UART RX | **GPIO1** = límite; **GPIO8** = UART RX (corregido en guía) |
| **BMM150 disponibilidad** | Comentario OSHWHUB: descatalogado/falsificaciones | Foro OSHWHUB | Considerar **QMC6309** + perfil `qmc6309` |
| **Huellas conectoras** | Nombres EasyEDA ≠ MPN único | Esquemático | Verificar en BOM clonada antes de pedir SMT |
| **BOM OSHWHUB web** | Export local parcial vs web vacía | Página actual | Tratar export local como snapshot; confirmar en clon |

---

## 8. Componentes reemplazables

| Componente | ¿Obligatorio Espressif? | Sustituto documentado |
|---|---|---|
| ESP32-C61-WROOM-1 | **Sí** | ESP32-C61-WROOM-1U (variante antena) |
| BMM150 | No | QMC6309 (excluyente en PCB) |
| QMC6309 | No | BMM150 |
| SS49E | No | Otros Hall lineales (recalibrar ADC) |
| TLV62569DBVR | No | Buck 3,3 V pin-compatible (verificar) |
| TPS2051BDBVR | No | Power switch USB similar |
| ULN2003A | No | Clones ULN2003 / TD62783 |
| AO3400A | No | MOSFET N SOT-23 equivalente |
| GT-TC072A-H060-L1 | No | Tact switch 6×6 mm |
| TM-8764-1 | No | Micro switch activo bajo similar |
| 24BYJ48 | No | Cualquier 24BYJ48 5V estándar |
| Pasivos R/C | No | Valores estándar 0402/0603 |
| LD2402, WS2812B | No (opcional) | Omitir si no se usan |

---

## 9. Riesgos para fabricar una réplica

| Riesgo | Severidad | Mitigación |
|---|---|---|
| **Sin Gerber en repo** | Alta | Clonar proyecto en OSHWHUB; pedir PCB+SMT en JLCPCB |
| **BOM incompleta (diodos, LED, L1)** | Alta | Exportar BOM desde EasyEDA tras clonar; no adivinar tipos |
| **WLCSP BMM150/QMC6309** | Alta | Usar servicio SMT; OSHWHUB lo advierte |
| **FFC invertido / cortocircuito** | Alta | Verificar dirección antes de insertar (paso 9 montaje) |
| **Orientación pogo pin** | Media | Extremo rojo = lado círculo blanco en PCB Sub |
| **Polaridad imanes** | Media | Probar atracción D6×5 ↔ D10×1,5 antes de cerrar carcasa |
| **BMM150 obsoleto/falso** | Media | Preferir QMC6309 según comunidad OSHWHUB |
| **Parámetros 3D no documentados** | Baja | Iterar en slicer; piezas estructurales en PLA/PETG |
| **Motor 28BYJ vs 24BYJ** | Media | Usar solo **24BYJ48** |
| **Documentación GPIO errónea** | Baja | Usar `tablas-referencia.md` y firmware como referencia |

---

## 10. Contradicciones detectadas y estado

| # | Contradicción | Estado en documentación |
|---|---|---|
| 1 | Imanes D10×1,5: 1 vs 2 unidades | Documentado en `lista-compra.md`; recomendación: **2** |
| 2 | Motor 24BYJ48 vs 28BYJ-48 | **Corregido** en `README_ES.md`, `tablas-referencia.md`, `arquitectura.md` (README firmware EN aún dice 28BYJ-48) |
| 3 | Homing 90° vs 95° | Firmware = 95°; anotar en ensamblaje |
| 4 | GPIO8 vs GPIO1 (fin de carrera) | **Corregido** en `guia-ensamblaje.md` |
| 5 | Condensadores 100 nF: cantidad 10 vs 9 | **Corregido** en `lista-compra.md` |
| 6 | BOM OSHWHUB web vacía vs export parcial | Documentado en esta auditoría |

---

## 11. Checklist previa a fabricación

### PCB

- [ ] Clonar proyecto [OSHWHUB esp-echoear-base](https://oshwhub.com/esp-college/esp-echoear-base)
- [ ] Exportar Gerber MainBoard + SubBoard V1.0
- [ ] Confirmar espesor **1,0 mm** en ambas placas
- [ ] Exportar BOM completa y posición de componentes (CPL) para SMT
- [ ] Revisar que solo se coloca **U5 o U6**, no ambos

### Componentes

- [ ] ESP32-C61-WROOM-1-N8R2 (×1)
- [ ] TLV62569DBVR, TPS2051BDBVR, ULN2003A, AO3400A (×1 c/u)
- [ ] BMM150 **o** QMC6309 (×1) + SS49E (×1)
- [ ] Pasivos según tablas §3 (valores verificados)
- [ ] D1–D7, LED1, L1: **pedir solo tras obtener MPN de OSHWHUB**
- [ ] BOOT GT-TC072A-H060-L1, SW1 TM-8764-1
- [ ] Conectores según huellas esquemático (MPN desde BOM clonada)
- [ ] Pogo pin 4P 2,5 mm con oreja
- [ ] Opcional: LD2402, WS2812B

### Impresión 3D

- [ ] Descargar 5 STEP de `3D_models/`
- [ ] Mapear piezas según tabla OSHWHUB (ver `guia-ensamblaje.md`)
- [ ] Definir material y orientación en slicer (**no documentado en repo**)
- [ ] Verificar tolerancias de asiento motor y rodamiento

### Tornillería

- [ ] M4×5 mm (×2)
- [ ] M2×4 mm (×2)
- [ ] M2×3 mm (×2)

### Imanes

- [ ] D10×1,5 mm (×**2** recomendado)
- [ ] D6×5 mm (×1)
- [ ] Verificar polaridad antes del cierre

### Cableado

- [ ] Cable motor 24BYJ48 → CN1 (1,25 mm 5P)
- [ ] FFC SH1.0 5P 60 mm, **misma dirección** en ambos extremos
- [ ] Motor: conector **en ángulo** (silk «Motor»)
- [ ] Sub Board: conector **recto** en Main

### Calibración (post-montaje)

- [ ] Flashear firmware con `MAG_SW_PROFILE` correcto
- [ ] Homing: giro hasta fin de carrera (GPIO1) + **95°**
- [ ] Calibración magnética (3 posiciones o perfil ss49e)
- [ ] UART 115200 con host ESP-VoCat
- [ ] Comprobar límite 500 mA en VBUS_OUT si alimenta host

---

## 12. Informe de reproducibilidad

Metodología: **52 líneas de aprovisionamiento** contabilizadas (ICs, pasivos por valor, diodos, LED, inductor, conectores, PCBs, motor, mecánica, 3D, cableado).

| Métrica | % | Descripción |
|---|---|---|
| **Diseño eléctrico documentado** | **~85%** | Valores R/C/L, ICs principales, arquitectura, GPIO, montaje |
| **MPN exactos en repo** | **~42%** | 22/52 líneas con MPN o referencia de pedido directo (ICs, BOOT, parte de pasivos OSHWHUB, motor, ESP32) |
| **Réplica solo con este repositorio** | **~38%** | Sin Gerber, sin MPN diodos/LED/L1/conectores, sin BOM web completa |
| **Réplica con repo + clon OSHWHUB** | **~78%** | Añade Gerber, BOM EasyEDA, MPN conectores y pasivos restantes (estimado) |
| **Réplica mecánica completa** | **~70%** | STEP disponibles; faltan parámetros de impresión oficiales |

### Elementos que **siempre** dependen de fuentes externas

1. **Gerber / pedido PCB** — clonar [OSHWHUB](https://oshwhub.com/esp-college/esp-echoear-base)
2. **BOM completa actualizada** — editor EasyEDA (pestaña BOM web vacía al 2026-07-08)
3. **MPN D1–D7, LED1, L1** — solo en proyecto EasyEDA clonado
4. **Parámetros slicer 3D** — no publicados en STEP ni OSHWHUB
5. **Host ESP-VoCat** — producto separado para prueba UART/magnética completa

### Conclusión

Con **únicamente este repositorio**, un fabricante puede entender el diseño, comprar la mayoría de semiconductores y pasivos por valor, imprimir mecánica e ensamblar siguiendo `guia-ensamblaje.md`, pero **no puede** pedir PCB ni completar SMT sin clonar OSHWHUB, ni identificar con certeza diodos, LED e inductor.

Con **repositorio + proyecto OSHWHUB clonado**, la reproducibilidad sube al **~78%**, quedando pendientes sobre todo parámetros de impresión 3D y validación mecánica fina.

---

*Auditoría elaborada sin inventar referencias. Los MPN parciales `0402WGF1` / `0402WGF4` en la exportación OSHWHUB están truncados y corresponden probablemente a `0402WGF1002` y `0402WGF4700` (UniOhm), pero no se han asignado como confirmados al no aparecer completos en ninguna fuente del repo.*

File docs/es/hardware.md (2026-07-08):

# Documentación de hardware — ESP-VoCat Base V1.0

> **Fuentes utilizadas en este análisis (sin suposiciones externas):**
> - `hardware/SCH_SCH-ESP-VoCat-Base-MainBoard-V1_0_2026-03-11.pdf`
> - `hardware/SCH_SCH-ESP-VoCat-Base-SubBoard-V1_0_2026-03-11.pdf`
> - `hardware/PCB_PCB-ESP-VoCat-Base-MainBoard-V1_0_2026-03-11.pdf`
> - `hardware/PCB_PCB-ESP-VoCat-Base-SubBoard-V1_0_2026-03-11.pdf`
> - `3D_models/` (archivos STEP/STP)
> - Código fuente: `stepper_motor.h`, `control_serial.h`, `magnetic_slide_switch.h`, `esp_vocat_rotating_base_main.c`
> - `docs/7726, 2155.txt` (exportación parcial de [OSHWHUB esp-echoear-base](https://oshwhub.com/esp-college/esp-echoear-base))
>
> **No disponible en el repositorio:** archivos Gerber, proyectos KiCad/Altium/EasyEDA editables, BOM completa exportable. Solo existen PDF de esquemático y PCB.

[← Guía central](../../README_ES.md) · [Tablas GPIO/firmware](tablas-referencia.md)

---

## 1. Descripción general

El hardware ESP-VoCat Base V1.0 (2026-03-11) es una base rotatoria compuesta por **dos PCB**:

| Placa | Archivo esquemático | Función principal |
|---|---|---|
| **Main Board** | `SCH-ESP-VoCat-Base-MainBoard-V1_0` | MCU, alimentación, motor, sensores, UART al host, expansiones |
| **Sub Board** | `SCH-ESP-VoCat-Base-SubBoard-V1_0` | Acoplamiento magnético al ESP-VoCat, fin de carrera de homing |

Ambas placas se montan sobre la mecánica impresa en 3D (`3D_models/`) con un motor **24BYJ48**, rodamiento **7×11×3 mm** y conectores magnéticos pogo pin.

```mermaid
flowchart TB
    subgraph Power["Alimentación"]
        USBC[USB Type-C 5V]
        TPS[TPS2051B 500mA]
        DCDC[TLV62569 5V→3.3V]
    end

    subgraph MainBoard["Main Board"]
        MCU[ESP32-C61-WROOM-1]
        ULN[ULN2003A]
        MAG[BMM150 / QMC6309]
        HALL[SS49E]
    end

    subgraph SubBoard["Sub Board"]
        POGO[Pogo pin 4P magnético]
        LSW[TM-8764-1 Fin de carrera]
    end

    subgraph Mech["Mecánica"]
        MOTOR[24BYJ48]
        BEARING[Rodamiento 7×11×3]
        HOST[ESP-VoCat Host]
    end

    USBC --> TPS
    USBC --> DCDC
    DCDC --> MCU
    TPS --> POGO
    MCU --> ULN --> MOTOR
    MCU --> MAG
    MCU --> HALL
    MCU <-->|UART1| HOST
    POGO <-->|VBUS/UART| HOST
    MainBoard <-->|FFC SH1.0 5P| SubBoard
    LSW -->|ANGLE_LIMIT_SW| MCU
    SubBoard --- BEARING
    MOTOR --- MainBoard
```

---

## 2. Main Board — función y bloques

Según el diagrama de bloques del esquemático (página 1):

| Bloque | Componente | Función |
|---|---|---|
| Entrada USB | `USB1` TYPE-C 16PIN | Alimentación 5 V y USB para depuración/expansión |
| Limitación de corriente | `U3` TPS2051BDBVR | Limita corriente a **500 mA** en salida `VBUS_OUT` hacia el host |
| Regulador DC-DC | `U2` TLV62569DBVR | Convierte 5 V → **3,3 V** (`VCC_3V3`) |
| MCU | `U1` ESP32-C61-WROOM-1 | Control, UART, I2C, ADC, FreeRTOS |
| Driver motor | `U4` ULN2003A | Excita bobinas del 24BYJ48 |
| Magnetómetro (opción A) | `U5` BMM150 | I2C — detección magnética (predeterminado en firmware) |
| Magnetómetro (opción B) | `U6` QMC6309 | I2C — alternativa; **soldar solo uno** |
| Hall lineal | `U7` SS49E | Salida analógica → ADC |
| LED RGB (expansión) | `CN4` + `Q1` AO3400A | Interfaz WS2812B con conversión de nivel |
| Radar presencia (expansión) | `H1` + LD2402 | UART2 — interfaz reservada |
| I2C expansión | `CN2` HC-1.25-4PLT | Bus I2C externo |
| Botón Boot | `BOOT` GT-TC072A-H060-L1 | GPIO9 — recalibración magnética |
| LED indicador | `LED1` | Con `R8`, `R9` 4,7 kΩ |
| Conector motor | `CN1` 1.25-5P WT | Cable plano al 24BYJ48 |
| Conector Sub Board | `CN3` WAFER-SHB1.0-5PLT-W1-P | FFC 1,0 mm 5 pines |

---

## 3. Sub Board — función

Según esquemático y documentación OSHWHUB (`docs/7726, 2155.txt`):

| Función | Implementación |
|---|---|
| Acoplamiento magnético al ESP-VoCat | `U1` — conector pogo pin macho **4 pines, 2,5 mm con oreja** (TXD, RXD, VBUS, GND) |
| Fin de carrera de homing | `SW1` TM-8764-1 → señal `ANGLE_LIMIT_SW` |
| Conexión a Main Board | `CN1` WAFER-SHB1.0-5PLT-W1-P (mismo tipo que `CN3` de Main Board) |
| Red divisora del interruptor | `R1` 51 kΩ, `R2` 100 kΩ |

La Sub Board se monta en el **rodamiento** del plato giratorio. El fin de carrera detecta el límite mecánico para la calibración angular del motor.

> **Orientación crítica (OSHWHUB):** al soldar el conector magnético en Sub Board, el extremo marcado en rojo debe coincidir con el círculo blanco de la PCB.

---

## 4. Alimentación

```mermaid
flowchart LR
    VBUS[USB Type-C VBUS 5V] --> TPS[TPS2051B U3<br/>límite 500mA]
    VBUS --> DCDC[TLV62569 U2<br/>Buck 3.3V]
    TPS --> VBUS_OUT[VBUS_OUT → Pogo / Host]
    DCDC --> VCC[VCC_3V3]
    VCC --> MCU[ESP32-C61]
    VCC --> MAG[BMM150 / QMC6309]
    VCC --> HALL[SS49E]
    VBUS --> ULN[ULN2003A / Motor 5V]
```

| Rail | Origen | Consumidores (según esquemático) |
|---|---|---|
| **VBUS** (5 V) | USB Type-C | Entrada DC-DC, ULN2003/motor, TPS2051B |
| **VCC_3V3** | TLV62569DBVR (`U2`) + `L1` 2,2 µH | ESP32-C61, BMM150, QMC6309, SS49E, lógica |
| **VBUS_OUT** | TPS2051BDBVR (`U3`) | Alimentación del ESP-VoCat vía pogo pin (máx. 500 mA) |

**Protección / condicionamiento de alimentación:**
- `TPS2051BDBVR`: limitación de corriente documentada a 500 mA para alimentación del host.
- Condensadores de desacoplo en VBUS y VCC_3V3 (`C1`–`C9`, `C5`, `C6`, `C7` 22 µF, etc.).
- Diodos `D1`–`D7` en rutas USB (protección según esquemático).
- Resistencias `R1`, `R4` 5,1 kΩ en líneas CC del USB Type-C.

**Requisito documentado (OSHWHUB / firmware):** alimentación mínima recomendada **5 V / 1 A** para operación del motor.

---

## 5. Interconexión entre placas

```mermaid
flowchart LR
    MB[Main Board CN3<br/>SH1.0 5P] <-->|FFC 60mm<br/>misma dirección| SB[Sub Board CN1<br/>SH1.0 5P]
    MB -->|Señales según PCB| SIG[GND, TX, RX, VBUS, ANGLE_LIMIT_SW]
```

| Señal (etiqueta PCB) | Origen | Destino | Función |
|---|---|---|---|
| `GND` | Común | Común | Referencia |
| `TX1` / `TXD` | Main GPIO29 | Sub → Pogo → Host | UART TX base |
| `RX1` / `RXD` | Main GPIO8 | Sub → Pogo → Host | UART RX base |
| `VBUS` | Main (tras TPS2051B) | Sub → Pogo | Alimentación host |
| `ANGLE_LIMIT_SW` | Sub `SW1` | Main GPIO1 | Fin de carrera (activo bajo) |

**Cable especificado (OSHWHUB):** terminal SH **1,0 mm**, **5 pines**, **60 mm**, ambos extremos en la **misma dirección**. Verificar orientación antes de insertar para evitar cortocircuitos.

**Conexión motor (Main Board):**
- `CN1` (1.25-5P WT) — conector en ángulo recto marcado **«Motor»**.
- Señales: `STEPPER_MOTOR_IN1`–`IN4` → ULN2003 → bobinas 24BYJ48.

---

## 6. ESP32-C61 — asignación de pines

### 6.1 Pines utilizados por el firmware (confirmado en código)

| GPIO | Etiqueta esquemático | Función | Módulo firmware | Interfaz |
|---|---|---|---|---|
| **GPIO 1** | `ANGLE_LIMIT_SW` | Fin de carrera homing | `esp_vocat_rotating_base_main.c` | Entrada digital, activo bajo |
| **GPIO 2** | `I2C_SDA` / `GPIO2` | Datos I2C sensor | `magnetic_slide_switch.h` | I2C0 SDA |
| **GPIO 3** | `I2C_SCL` / `GPIO3` | Reloj I2C sensor | `magnetic_slide_switch.h` | I2C0 SCL |
| **GPIO 5** | `HALL_VOUT` / `GPIO5` | Salida analógica Hall | `magnetic_slide_switch.h` | ADC_CHANNEL_3 |
| **GPIO 8** | `RX1` / `GPIO8` | UART RX | `control_serial.h` | UART1 RX |
| **GPIO 9** | `GPIO9` / `BOOT` | Botón Boot | `esp_vocat_rotating_base_main.c` | Entrada, activo bajo |
| **GPIO 25** | `STEPPER_MOTOR_IN4` | Motor IN4 | `stepper_motor.h` | Salida digital |
| **GPIO 26** | `STEPPER_MOTOR_IN3` | Motor IN3 | `stepper_motor.h` | Salida digital |
| **GPIO 27** | `STEPPER_MOTOR_IN2` | Motor IN2 | `stepper_motor.h` | Salida digital |
| **GPIO 28** | `STEPPER_MOTOR_IN1` | Motor IN1 | `stepper_motor.h` | Salida digital |
| **GPIO 29** | `TX1` / `GPIO29` | UART TX | `control_serial.h` | UART1 TX |

### 6.2 Pines asignados en hardware pero no usados por el firmware base actual

| GPIO | Etiqueta esquemático | Hardware conectado | Notas |
|---|---|---|---|
| **GPIO 4** | `RGB_CTRL` | `CN4` WS2812B vía `Q1` AO3400A | Expansión LED RGB — sin driver en firmware analizado |
| **GPIO 7** | `LD2402_IO` | Header `H1` pin IO | Radar LD2402 — sin driver en firmware analizado |
| **GPIO 12** | `GPIO12` | Rutas USB D+/D- (esquemático) | No referenciado en firmware |
| **GPIO 13** | `GPIO13` | Rutas USB D+/D- (esquemático) | No referenciado en firmware |
| **GPIO 22** | `LD2402_RX` | Header `H1` | UART2 expansión LD2402 |
| **GPIO 23** | `LD2402_TX` | Header `H1` | UART2 expansión LD2402 |

### 6.3 Pines listados en esquemático sin asignación clara en firmware

| GPIO | Estado |
|---|---|
| GPIO 0 | Circuito `ESP_EN` / reset (no usado como IO en firmware) |
| GPIO 6 | Aparece en lista de pines del módulo; **sin conexión funcional identificada en esquemático extraído** |
| GPIO 24 | Aparece en pinout del módulo; **sin uso en firmware ni etiqueta de red clara** |

> Para confirmar GPIO 6 y GPIO 24, consultar el netlist completo en el proyecto EasyEDA original en [OSHWHUB](https://oshwhub.com/esp-college/esp-echoear-base) (no incluido en este repositorio).

### 6.4 Diagrama de interfaces del MCU

```mermaid
flowchart TB
    MCU[ESP32-C61-WROOM-1]

    MCU -->|UART1 115200| UART[GPIO8 RX / GPIO29 TX]
    MCU -->|I2C 400kHz| I2C[GPIO2 SDA / GPIO3 SCL]
    MCU -->|ADC| ADC[GPIO5 HALL_VOUT]
    MCU -->|GPIO x4| MOTOR[GPIO25-28 → ULN2003]
    MCU -->|GPIO| LIM[GPIO1 ANGLE_LIMIT_SW]
    MCU -->|GPIO| BOOT[GPIO9]
    MCU -.->|UART2 reserva| LD[GPIO22/23 LD2402]
    MCU -.->|GPIO reserva| RGB[GPIO4 WS2812B]
    MCU -.->|I2C reserva| EXP[CN2 I2C Header]
```

---

## 7. Circuito del motor paso a paso

### 7.1 Componentes

| Ref. | Componente | Encapsulado / tipo | Función |
|---|---|---|---|
| — | 24BYJ48 | Motor paso a paso 5 V | Actuador mecánico (externo a PCB) |
| `U4` | ULN2003A | DIP/SOP Darlington array | Driver de corriente para bobinas |
| `CN1` | 1.25-5P WT | Conector wafer | Interfaz cable motor |
| `C10` | 100 nF | — | Desacoplo en rama motor/VBUS |

### 7.2 Conexión eléctrica (esquemático → firmware)

```mermaid
flowchart LR
    subgraph ESP32
        G25[GPIO28 IN1]
        G26[GPIO27 IN2]
        G27[GPIO26 IN3]
        G28[GPIO25 IN4]
    end

    subgraph ULN[ULN2003A U4]
        IN1[1B-1C]
        IN2[2B-2C]
        IN3[3B-3C]
        IN4[4B-4C]
    end

    subgraph MOTOR[24BYJ48]
        COILS[4 bobinas + COM]
    end

    G25 --> IN1 --> COILS
    G26 --> IN2 --> COILS
    G27 --> IN3 --> COILS
    G28 --> IN4 --> COILS
    VBUS[5V VBUS] --> ULN
```

| Señal PCB | GPIO ESP32 | Entrada ULN2003 | Firmware |
|---|---|---|---|
| `STEPPER_MOTOR_IN1` | GPIO 28 | 1B | `IN1_PIN` |
| `STEPPER_MOTOR_IN2` | GPIO 27 | 2B | `IN2_PIN` |
| `STEPPER_MOTOR_IN3` | GPIO 26 | 3B | `IN3_PIN` |
| `STEPPER_MOTOR_IN4` | GPIO 25 | 4B | `IN4_PIN` |

### 7.3 Secuencia de control (firmware)

El firmware usa **half-step de 8 pasos** (`stepper_motor.c`):
- Secuencias `step_sequence_cw[8][4]` y `step_sequence_ccw[8][4]`.
- Aceleración/desaceleración: `STEPPER_ACCEL_STEPS = 30`, `STEPPER_DECEL_STEPS = 30`.
- Tras cada movimiento: `stepper_motor_power_off()` desenergiza bobinas.

**Alimentación del motor:** 5 V (`VBUS`) a través del ULN2003A, coherente con 24BYJ48 DC 5V documentado en OSHWHUB.

---

## 8. Circuito del sensor magnético

### 8.1 BMM150 (`U5`) — opción predeterminada

| Parámetro | Valor | Fuente |
|---|---|---|
| Interfaz | I2C | Esquemático + firmware |
| Dirección I2C | `0x10` | `magnetic_slide_switch.h` |
| Chip ID | `0x32` | `magnetic_slide_switch.h` |
| Pines I2C | SDA=GPIO2, SCL=GPIO3 | Esquemático + firmware |
| Alimentación | VCC_3V3 | Esquemático |
| Desacoplo | `C11`, `C12` 100 nF | Esquemático |
| Encapsulado | WLCSP (OSHWHUB) | Documentación OSHWHUB |

### 8.2 QMC6309 (`U6`) — alternativa

| Parámetro | Valor | Fuente |
|---|---|---|
| Dirección I2C | `0x7C` | `magnetic_slide_switch.h` |
| Chip ID | `0x90` | `magnetic_slide_switch.h` |
| Desacoplo | `C13` 100 nF | Esquemático |
| Selección | **Solo uno** BMM150 o QMC6309 soldado | OSHWHUB + `Kconfig` |

> Ambos comparten el bus I2C (`I2C_SCL`, `I2C_SDA`). Son pads alternativos en la misma PCB.

### 8.3 SS49E (`U7`) — sensor Hall lineal

| Parámetro | Valor | Fuente |
|---|---|---|
| Tipo | Hall lineal, salida analógica | Esquemático |
| Señal | `HALL_VOUT` → GPIO5 | Esquemático + firmware |
| ADC | `ADC_CHANNEL_3` | `magnetic_slide_switch.h` |
| Desacoplo / filtro | `C14` 100 nF, `C15` 10 nF | Esquemático |
| Alimentación | VCC_3V3 | Esquemático |
| Limitación firmware | Solo eventos SLIDE_UP / SLIDE_DOWN | `Kconfig` + README |

### 8.4 Pull-ups I2C

El esquemático extraído **no lista resistencias pull-up I2C dedicadas** con designador visible en la página 2. Los pull-ups pueden estar:
- Integrados en el módulo ESP32-C61, o
- En otra hoja/no extraídos correctamente del PDF.

> **Dato no confirmado en PDF extraído:** valor de pull-ups I2C. Verificar en proyecto EasyEDA en OSHWHUB.

```mermaid
flowchart TB
    MCU[ESP32-C61 GPIO2/3]
    MCU -->|I2C_SDA/SCL| BUS[I2C Bus]
    BUS --> BMM[U5 BMM150 0x10]
    BUS --> QMC[U6 QMC6309 0x7C<br/>alternativa]
    MCU -->|GPIO5 ADC| HALL[U7 SS49E HALL_VOUT]
```

---

## 9. Sistema de calibración — fin de carrera

### 9.1 Hardware

| Ref. | Componente | Tipo | Ubicación |
|---|---|---|---|
| `SW1` | TM-8764-1 | Interruptor de límite (fin de carrera) | Sub Board |
| `R1` | 51 kΩ | Divisor / pull | Sub Board |
| `R2` | 100 kΩ | Divisor / pull | Sub Board |
| Señal | `ANGLE_LIMIT_SW` | Hacia Main Board GPIO1 | FFC 5P |

### 9.2 Conexión eléctrica

```mermaid
flowchart LR
    SW[SW1 TM-8764-1<br/>Sub Board] -->|ANGLE_LIMIT_SW| CN[CN3/CN1 FFC]
    CN --> GPIO1[GPIO1 ESP32-C61]
    R1[R1 51k] --- SW
    R2[R2 100k] --- SW
```

### 9.3 Lógica de firmware

Fuente: `esp_vocat_rotating_base_main.c`

| Parámetro | Valor |
|---|---|
| Pin | `GPIO_NUM_1` |
| Nivel activo | Bajo (`active_level = 0`) |
| Detección | Componente `iot_button` → semáforo binario |
| Secuencia homing | Girar -5° en bucle hasta pulsar fin de carrera |
| Tras activación | Esperar 200 ms → girar +95° → `stepper_motor_power_off()` |
| Timeout | 2000 ms → modo fallback (+95° sin fin de carrera) |

---

## 10. Lista de materiales (BOM)

> **Guía de fabricación completa:** [BOM.md](BOM.md) (tabla detallada con MPN y alternativas) · [lista-compra.md](lista-compra.md) · [guia-ensamblaje.md](guia-ensamblaje.md)

### 10.1 Main Board — componentes activos (esquemático PDF)

| Ref. | Componente | Valor / modelo | Encapsulado | Función |
|---|---|---|---|---|
| `U1` | ESP32-C61-WROOM-1 | — | Módulo Wi-Fi | MCU principal |
| `U2` | TLV62569DBVR | Buck DC-DC | SOT-23-6 | 5 V → 3,3 V |
| `U3` | TPS2051BDBVR | Límite 500 mA | SOT-23-5 | Switch VBUS hacia host |
| `U4` | ULN2003A | Darlington array | — | Driver motor paso a paso |
| `U5` | BMM150 | Magnetómetro 3 ejes | WLCSP | Sensor magnético I2C (opción A) |
| `U6` | QMC6309 | Magnetómetro 3 ejes | WLCSP | Sensor magnético I2C (opción B) |
| `U7` | SS49E | Hall lineal | — | Sensor Hall analógico |
| `Q1` | AO3400A | MOSFET N | — | Control WS2812B / nivel |
| `USB1` | TYPE-C 16PIN 2MD(073) | USB Type-C | — | Entrada alimentación |
| `L1` | Inductor | 2,2 µH | — | DC-DC |
| `BOOT` | GT-TC072A-H060-L1 | Táctil | — | Botón Boot |
| `LED1` | LED | — | — | Indicador |
| `D1`–`D7` | Diodos | — | — | Protección USB / señales |
| `CN1` | 1.25-5P WT | 5 pines 1,25 mm | Wafer | Conector motor |
| `CN3` | WAFER-SHB1.0-5PLT-W1-P | 5 pines 1,0 mm | — | Cable a Sub Board |
| `CN2` | HC-1.25-4PLT | 4 pines 1,25 mm | — | Expansión I2C |
| `CN4` | HC-1.25-3PLT | 3 pines 1,25 mm | — | Expansión WS2812B |
| `H1` | PZ254V-11-05P | Header 5 pines | — | Interfaz LD2402 |

### 10.2 Main Board — pasivos (esquemático PDF)

| Ref. | Valor | Función inferida del esquemático |
|---|---|---|
| `C1`, `C8` | 10 µF | Desacoplo DC-DC / bulk 3V3 |
| `C3` | 10 µF | Desacoplo |
| `C7` | 22 µF | Entrada/salida DC-DC |
| `C9` | 1 µF | Desacoplo |
| `C2`, `C4`, `C5`, `C6`, `C10`–`C15` | 100 nF / 10 nF (`C15`) | Desacoplo por IC/ruta |
| `R1`, `R4` | 5,1 kΩ | USB Type-C CC |
| `R2` | 100 kΩ | Retroalimentación DC-DC |
| `R5` | 22,1 kΩ | Retroalimentación DC-DC |
| `R3`, `R6` | 10 kΩ | Circuito EN / GPIO9 |
| `R7` | 1 kΩ | — |
| `R8`, `R9` | 4,7 kΩ | LED |
| `R10`, `R11` | 10 kΩ | Polarización `Q1` |

### 10.3 Sub Board (esquemático PDF)

| Ref. | Componente | Valor | Función |
|---|---|---|---|
| `CN1` | WAFER-SHB1.0-5PLT-W1-P | 5P 1,0 mm | Conexión a Main Board |
| `SW1` | TM-8764-1 | — | Fin de carrera |
| `U1` | Conector pogo pin magnético | 4P 2,5 mm | Acoplamiento ESP-VoCat |
| `R1` | 51 kΩ | — | Red del interruptor |
| `R2` | 100 kΩ | — | Red del interruptor |

### 10.4 BOM parcial OSHWHUB (archivo `docs/7726, 2155.txt`)

La exportación web de OSHWHUB en el repositorio está **incompleta** (solo algunos pasivos):

| ID | Valor | Designadores | Huella | Cant. | Fab |
|----|---|---|---|---|-----|
| 1 | 10 µF | C3, C1, C8 | C0603 | 3 | CL10A106K |
| 2 | 100 nF | C4,C2,C10,C11,C12,C13,C14,C5,C6 | C0402 | 9 | CL05B104K |
| 3 | 1 µF | C9 | C0402 | 1 | CL05A105K |
| 4 | 10 kΩ | R3, R6, R10, R11 | R0402 | 4 | 0402WGF1 |
| 5 | 4,7 kΩ | R8, R9 | R0402 | 2 | 0402WGF4 |

> **BOM completa:** descargar desde [OSHWHUB — esp-echoear-base](https://oshwhub.com/esp-college/esp-echoear-base). No está incluida como archivo estructurado en este repositorio.

### 10.5 Componentes mecánicos y externos (OSHWHUB + `docs/7726, 2155.txt`)

| # | Componente | Especificación |
|---|---|---|
| 1 | Motor paso a paso | 24BYJ48 DC 5V |
| 2 | Rodamiento | ID 7 mm, OD 11 mm, H 3 mm |
| 3 | Imán deslizador | D6×5 mm (1 ud.) |
| 4 | Imán acoplamiento | D10×1,5 mm (2 ud. en carcasa) |
| 5 | Cable FFC | SH 1,0 mm 5P, 60 mm, misma dirección |
| 6 | Tornillos | M4×5, M2×4, M2×3 |
| 7 | Radar (opcional) | LD2402 |
| 8 | Conector magnético | Pogo pin macho 4P 2,5 mm con oreja |

**Espesor PCB recomendado (OSHWHUB):** 1,0 mm.

---

## 11. Modelos 3D (`3D_models/`)

| Archivo | Origen CAD | Función inferida (nombre + OSHWHUB) |
|---|---|---|
| `ESP-VoCat catbase cover 2025-11-22.STEP` | SolidWorks 2017 | Carcasa exterior superior |
| `ESP-VoCat catbase platform top 2025-11-22.STEP` | SolidWorks 2017 | Cubierta superior del plato giratorio |
| `ESP-VoCat catbase ball only 2025-11-22.STEP` | SolidWorks 2017 | Componente esférico / detalle mecánico |
| `ESP-VoCat_catbase_20251128.stp` | — | Conjunto o carcasa principal (versión 2025-11-28) |
| `ESP-VoCat_catbase_platform_btm_20251128.stp` | — | Cubierta inferior del plato giratorio (versión 2025-11-28) |

### Relación mecánica ↔ electrónica (OSHWHUB, `docs/7726, 2155.txt`)

| Pieza 3D / mecánica | Componente electrónico |
|---|---|
| Carcasa exterior | Aloja Main Board, motor, rodamiento |
| Plato giratorio (top + bottom) | Monta Sub Board y rodamiento 7×11×3 |
| Ranura en carcasa | Rodamiento |
| Alojamiento motor | 24BYJ48 fijado con tornillos M4×5 |
| Interruptor deslizante 3D + imán D6×5 | Interacción con BMM150/QMC6309 en Main Board |
| Imanes D10×1,5 en carcasa | Acoplamiento magnético con ESP-VoCat |
| Sub Board en plato giratorio | Pogo pin hacia host + fin de carrera |

### Secuencia de montaje (OSHWHUB)

1. Ensamblar imanes D10×1,5 en carcasa (atención a polaridad).
2. Instalar rodamiento 7×11×3 en ranura 3D.
3. Instalar motor 24BYJ48 (M4×5, apretar tras montar plato).
4. Instalar Sub Board en cubierta inferior del plato.
5. Instalar cubierta superior del plato (M2×3).
6. Insertar cable SH1.0 5P en interfaz del plato.
7. Montar plato en eje del motor; apretar tornillos motor.
8. Fijar Main Board a carcasa (M2×4).
9. Conectar cable motor (CN1, ángulo recto «Motor») y FFC Sub Board (CN3).
10. Instalar imán D6×5 en deslizador magnético 3D; calibrar al encender.

---

## 12. Archivos de diseño disponibles y ausentes

| Tipo | Disponible en repo | Archivos |
|---|---|---|
| Esquemático PDF | Sí | `hardware/SCH_*MainBoard*.pdf`, `SCH_*SubBoard*.pdf` |
| PCB PDF | Sí | `hardware/PCB_*MainBoard*.pdf`, `PCB_*SubBoard*.pdf` |
| Gerber | **No** | Debería estar en OSHWHUB al pedir fabricación |
| KiCad / Altium / EasyEDA editable | **No** | Proyecto fuente en [OSHWHUB](https://oshwhub.com/esp-college/esp-echoear-base) |
| BOM CSV/Excel completa | **No** | Parcial en `docs/7726, 2155.txt`; completa en OSHWHUB |
| Modelos 3D | Sí | `3D_models/*.STEP`, `*.stp` |

---

## 13. Diagramas eléctricos adicionales

### 13.1 Arquitectura eléctrica completa

```mermaid
flowchart TB
    subgraph Input
        USBC[USB Type-C]
    end

    subgraph MainBoard
        DCDC[TLV62569 3V3]
        TPS[TPS2051B]
        MCU[ESP32-C61]
        ULN[ULN2003A]
        SENS[BMM150 / QMC6309 / SS49E]
    end

    subgraph SubBoard
        POGO[Pogo 4P]
        LIM[TM-8764-1]
    end

    subgraph Actuators
        MOTOR[24BYJ48]
    end

    subgraph Host
        VOCAT[ESP-VoCat]
    end

    USBC --> DCDC --> MCU
    USBC --> TPS --> POGO --> VOCAT
    USBC --> ULN --> MOTOR
    MCU --> ULN
    MCU --> SENS
    MCU <-->|UART| VOCAT
    LIM --> MCU
    MCU <-->|FFC| SubBoard
```

### 13.2 Flujo de alimentación

Ver sección 4.

### 13.3 Conexión del sensor magnético

Ver sección 8.

### 13.4 Conexión del interruptor Home

Ver sección 9.

---

## 14. Fabricación de réplica — checklist mínimo

Basado exclusivamente en documentación del repositorio:

- [ ] Pedir PCB Main Board + Sub Board (OSHWHUB/JLCPCB, espesor **1,0 mm**)
- [ ] Soldar componentes SMT (considerar WLCSP de BMM150/QMC6309)
- [ ] Soldar **solo uno**: BMM150 **o** QMC6309
- [ ] Imprimir piezas 3D desde `3D_models/`
- [ ] Adquirir motor 24BYJ48, rodamiento 7×11×3, imanes, cable SH1.0 5P
- [ ] Ensamblar según secuencia OSHWHUB (sección 11)
- [ ] Flashear firmware: `idf.py set-target esp32c61 && idf.py flash`
- [ ] Configurar sensor en `menuconfig` coherente con hardware soldado
- [ ] Ejecutar calibración magnética (3 posiciones, ~500 ms cada una)

---

## 15. Referencias cruzadas

| Tema | Documento |
|---|---|
| GPIO y UART en firmware | [tablas-referencia.md](tablas-referencia.md) |
| Arranque y homing | [arranque-firmware.md](arranque-firmware.md) |
| Arquitectura software | [arquitectura.md](arquitectura.md) |
| Problemas de hardware | [troubleshooting.md](troubleshooting.md) |
| Proyecto OSHWHUB | https://oshwhub.com/esp-college/esp-echoear-base |

---

*Documento generado a partir de extracción de texto de PDFs en `hardware/`, metadatos STEP, firmware y exportación OSHWHUB presente en el repositorio. Versión hardware: V1.0 (2026-03-11).*

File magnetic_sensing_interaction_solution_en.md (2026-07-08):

# Magnetic Sensing Interaction Solution Introduction

[Español](./magnetic_sensing_interaction_solution_es.md) | [English](./magnetic_sensing_interaction_solution_en.md)

## 1. Overview

The ESP-VoCat base uses a magnetic slide switch to provide rich interaction control. Different slider positions change the local magnetic field, and the firmware continuously samples sensor data to detect slider actions. Detected events are reported to ESP-VoCat via UART.

## 2. Event Types by Demo Project

### 2.1 Bell Slider Event Detection Demo
Project: [`software/esp_vocat_rotating_base_bell_event_detection`](./software/esp_vocat_rotating_base_bell_event_detection/)

Supported events:

- `SLIDE_DOWN`: Slider is moved from the upper position to the lower position.
- `SLIDE_UP`: Slider is moved from the lower position to the upper position.
- `REMOVE_FROM_UP`: Slider is removed from the upper position.
- `REMOVE_FROM_DOWN`: Slider is removed from the lower position.
- `PLACE_FROM_UP`: Slider is placed into the upper position.
- `PLACE_FROM_DOWN`: Slider is placed into the lower position.
- `SINGLE_CLICK`: A single-click action is detected when the slider stays at the lower position.

### 2.2 iPhone Detection Demo
Project: [`software/esp_vocat_rotating_base_iphone_detection`](./software/esp_vocat_rotating_base_iphone_detection/)

Supported events:

- `IPHONE_LEAN_FRONT`: iPhone leans against the front side of the base.
- `IPHONE_LEAN_FRONT_DETACHED`: iPhone leaves the front side of the base.
- `IPHONE_UNDER_BASE`: iPhone is placed under the base and enters a valid detected state.
- `IPHONE_UNDER_BASE_DETACHED`: iPhone is removed from under the base.

### 2.3 Magnetic Accessory Detection Demo
Project: [`software/esp_vocat_rotating_base_magnetic_accessory_detection`](./software/esp_vocat_rotating_base_magnetic_accessory_detection/)

Supported events:

- `FISH_ATTACHED`: Fish accessory is detected as attached.
- `FISH_DETACHED`: Fish accessory is removed from the base.
- `PAIRING`: Pairing condition is detected and pairing mode is entered.
- `PAIRING_CANCELLED`: Pairing condition disappears and pairing mode is exited.
- `ICE_CREAM_ATTACHED`: Ice-cream accessory is detected as attached.
- `ICE_CREAM_DETACHED`: Ice-cream accessory is removed from the base.
- `DONUT_ATTACHED`: Donut accessory is detected as attached.
- `DONUT_DETACHED`: Donut accessory is removed from the base.

> Note: Event sets are defined by the `magnetic_slide_switch` profile selected by each demo. The source code enum definition is the final reference.

## 3. Sensor Support

One of the following sensors can be used:

- BMM150 3-axis magnetometer (default)
- QMC6309 3-axis magnetometer
- Linear Hall sensor

## 4. Notes

1. Different demo projects expose different event sets. Switch project to switch behavior.
2. Run full auto-calibration before first use to capture baseline values for up/down/removed states.
3. Calibration data is persisted in NVS and survives power cycles.
4. Recalibration can be triggered by UART command or by long-pressing the base Boot button.

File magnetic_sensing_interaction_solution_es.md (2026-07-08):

# Introducción a la solución de interacción por sensado magnético

[Español](./magnetic_sensing_interaction_solution_es.md) | [English](./magnetic_sensing_interaction_solution_en.md)

> Documentación ampliada: [Guía central](README_ES.md) · [Arquitectura de perfiles](docs/es/perfiles.md) · [Tablas de eventos UART](docs/es/tablas-referencia.md#eventos-magnéticos-por-perfil)

## 1. Descripción general

La base ESP-VoCat utiliza un interruptor deslizante magnético para ofrecer un control de interacción enriquecido. Las distintas posiciones del deslizador modifican el campo magnético local; el firmware muestrea continuamente los datos del sensor para detectar las acciones del deslizador. Los eventos detectados se reportan a ESP-VoCat mediante UART.

## 2. Tipos de eventos por proyecto de demostración

### 2.1 Demostración de eventos del deslizador tipo campana
Proyecto: [`software/esp_vocat_rotating_base_bell_event_detection`](./software/esp_vocat_rotating_base_bell_event_detection/)

Eventos soportados:

- `SLIDE_DOWN`: El deslizador se mueve de la posición superior a la inferior.
- `SLIDE_UP`: El deslizador se mueve de la posición inferior a la superior.
- `REMOVE_FROM_UP`: El deslizador se retira de la posición superior.
- `REMOVE_FROM_DOWN`: El deslizador se retira de la posición inferior.
- `PLACE_FROM_UP`: El deslizador se coloca en la posición superior.
- `PLACE_FROM_DOWN`: El deslizador se coloca en la posición inferior.
- `SINGLE_CLICK`: Se detecta una acción de clic simple cuando el deslizador permanece en la posición inferior.

### 2.2 Demostración de detección de iPhone
Proyecto: [`software/esp_vocat_rotating_base_iphone_detection`](./software/esp_vocat_rotating_base_iphone_detection/)

Eventos soportados:

- `IPHONE_LEAN_FRONT`: El iPhone se apoya contra el frente de la base.
- `IPHONE_LEAN_FRONT_DETACHED`: El iPhone se separa del frente de la base.
- `IPHONE_UNDER_BASE`: El iPhone se coloca debajo de la base y entra en estado de detección válido.
- `IPHONE_UNDER_BASE_DETACHED`: El iPhone se retira de debajo de la base.

### 2.3 Demostración de detección de accesorios magnéticos
Proyecto: [`software/esp_vocat_rotating_base_magnetic_accessory_detection`](./software/esp_vocat_rotating_base_magnetic_accessory_detection/)

Eventos soportados:

- `FISH_ATTACHED`: Se detecta el accesorio de pez adherido.
- `FISH_DETACHED`: El accesorio de pez se retira de la base.
- `PAIRING`: Se detecta la condición de emparejamiento y se entra en modo de emparejamiento.
- `PAIRING_CANCELLED`: La condición de emparejamiento desaparece y se sale del modo de emparejamiento.
- `ICE_CREAM_ATTACHED`: Se detecta el accesorio de helado adherido.
- `ICE_CREAM_DETACHED`: El accesorio de helado se retira de la base.
- `DONUT_ATTACHED`: Se detecta el accesorio de dona adherido.
- `DONUT_DETACHED`: El accesorio de dona se retira de la base.

> **Nota:** Los conjuntos de eventos están definidos por el perfil `magnetic_slide_switch` seleccionado en cada demostración. La definición del enum en el código fuente es la referencia final.

## 3. Sensores compatibles

Se puede utilizar uno de los siguientes sensores:

- Magnetómetro de 3 ejes BMM150 (predeterminado)
- Magnetómetro de 3 ejes QMC6309
- Sensor Hall lineal

## 4. Notas de uso

1. Cada proyecto de demostración expone un conjunto de eventos diferente. Cambie de proyecto para cambiar el comportamiento de detección.
2. Antes del primer uso, ejecute la calibración automática completa para capturar los valores de referencia de los estados superior, inferior y retirado.
3. Los datos de calibración se almacenan de forma persistente en NVS y sobreviven a los ciclos de encendido.
4. La recalibración puede activarse mediante comando UART o manteniendo pulsado el botón Boot de la base.

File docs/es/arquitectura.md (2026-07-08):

# Arquitectura del sistema

> Derivado de: `app_main`, `control_serial.c`, `stepper_motor.c`, `magnetic_slide_switch/`, `CMakeLists.txt` de cada proyecto.

[← Volver a la guía principal](../../README_ES.md) · [Tablas de referencia](tablas-referencia.md)

---

## 1. Arquitectura general

```mermaid
flowchart TB
    subgraph Host["ESP-VoCat (Host)"]
        SSL[Localización de fuente sonora]
        UI[Interfaz / animaciones]
        HOST_UART[UART TX/RX]
    end

    subgraph Base["Base rotatoria (ESP32-C61)"]
        APP[app_main]
        UART[control_serial]
        MOTOR[stepper_motor]
        MAG[magnetic_slide_switch]
        NVS[(NVS Flash)]

        APP --> UART
        APP --> MOTOR
        APP --> MAG
        MAG --> NVS
        UART --> MOTOR
        MAG --> UART
    end

    subgraph HW["Hardware"]
        STEPPER[24BYJ48 + ULN2003]
        LIMIT[Fin de carrera GPIO1]
        SENSOR[BMM150 / QMC6309 / Hall]
        BOOT[Botón Boot GPIO9]
    end

    HOST_UART <-->|115200 bps| UART
    MOTOR --> STEPPER
    APP --> LIMIT
    APP --> BOOT
    MAG --> SENSOR
```

La base actúa como **periférico inteligente**: recibe comandos de ángulo y acción del host ESP-VoCat, ejecuta movimiento mecánico y reporta eventos del interruptor magnético de vuelta por UART.

---

## 2. Hardware, firmware y componentes compartidos

```mermaid
flowchart LR
    subgraph Physical["Capa física"]
        PCB[PCB Main + Sub Board]
        MECH[3D_models / mecánica]
        MOTOR_HW[Motor + fin de carrera]
        MAG_HW[Sensor magnético]
    end

    subgraph FW["Capa firmware (ESP-IDF)"]
        subgraph Apps["Aplicaciones (4 proyectos)"]
            A1[esp_vocat_rotating_base]
            A2[bell_event_detection]
            A3[iphone_detection]
            A4[magnetic_accessory_detection]
        end

        subgraph Common["common_components"]
            SM[stepper_motor]
            CS[control_serial]
            MSS[magnetic_slide_switch]
            BMM[BMM150_SensorAPI]
        end

        subgraph IDF["ESP-IDF / drivers"]
            GPIO_DRV[driver/gpio]
            UART_DRV[driver/uart]
            I2C_DRV[driver/i2c / i2c_bus]
            ADC_DRV[driver/adc]
            NVS_DRV[nvs_flash]
            BTN[espressif/button]
        end
    end

    PCB --> MOTOR_HW
    PCB --> MAG_HW
    MECH --> MOTOR_HW

    A1 & A2 & A3 & A4 --> SM
    A1 & A2 & A3 & A4 --> CS
    A1 & A2 & A3 & A4 --> MSS
    MSS --> BMM

    SM --> GPIO_DRV
    CS --> UART_DRV
    MSS --> I2C_DRV
    MSS --> ADC_DRV
    MSS --> NVS_DRV
    A1 --> BTN
```

**Nota sobre capas HAL:** Este repositorio no define un directorio `hal/` explícito. La abstracción de hardware se implementa dentro de cada componente (`stepper_motor` encapsula GPIO; `magnetic_slide_switch` encapsula I2C/ADC; `control_serial` encapsula UART), apoyándose en los drivers oficiales de ESP-IDF.

---

## 3. Flujo de comunicación UART

```mermaid
sequenceDiagram
    participant Host as ESP-VoCat
    participant UART as uart_cmd_receive_task
    participant Motor as stepper_motor
    participant Mag as magnetic_slide_switch

    Note over Host,Mag: Recepción de comando (Host → Base)
    Host->>UART: Trama AA 55 ...
    UART->>UART: Sincronizar cabecera 0xAA 0x55
    UART->>UART: Validar longitud y checksum
    alt CMD 0x01 Ángulo
        UART->>Motor: stepper_rotate_angle_with_accel(diff)
        Motor-->>UART: Rotación completada
        UART->>Motor: stepper_motor_power_off()
    else CMD 0x02 Acción
        UART->>Motor: stepper_shake_head / look_around / ...
        Motor-->>UART: Acción completada
        UART->>Host: CMD 0x02 ACTION_COMPLETE (0x0010)
    else CMD 0x03 Recalibrar
        UART->>Mag: magnetic_slide_switch_start_recalibration()
    end

    Note over Host,Mag: Notificación de evento (Base → Host)
    Mag->>Host: CMD 0x03 + código de evento
    Note over UART,Host: magnetic_detect_task envía CMD 0x00 cada 500 ms
```

**Reglas de parsing** (`control_serial.c`):
1. Búsqueda de cabecera `0xAA 0x55` en el buffer recibido.
2. Lectura de `LEN` y validación de trama completa.
3. Cálculo de checksum **antes** de ejecutar el comando.
4. Para ángulo: rango válido 0–180°; posición absoluta interna inicializada en 90°.

---

## 4. Flujo de inicialización del sistema

```mermaid
flowchart TD
    START([Reset / Power-on]) --> NVS[nvs_flash_init]
    NVS -->|Error NVS| ERASE[nvs_flash_erase + reinit]
    ERASE --> SEM[Semáforo fin de carrera]
    NVS --> SEM
    SEM --> GPIO_MOTOR[stepper_motor_gpio_init]
    GPIO_MOTOR --> LIMIT_INIT[base_angle_limit_switch_init]
    LIMIT_INIT --> BOOT_INIT[boot_button_init]
    BOOT_INIT --> UART_INIT[control_serial_init]
    UART_INIT --> MAG_TASK[control_serial_start_magnetic_detect_task]
    MAG_TASK --> CAL_TASK[xTaskCreate base_calibration_task]
    CAL_TASK --> MAG_START[magnetic_slide_switch_start]

    MAG_START --> I2C_INIT[Inicializar I2C + sensor]
    I2C_INIT --> MAG_READ[xTaskCreate magnetometer_data_read_task]
    MAG_READ --> CAL_MAG[xTaskCreate magnetometer_calibration_task]
    CAL_MAG --> WAIT_CAL{Calibración magnética<br/>en NVS o automática}
    WAIT_CAL -->|Completa| DETECT[xTaskCreate slide_switch_event_detect_task]
    DETECT --> READY([Modo operativo])

    CAL_TASK --> HOMING[Girar izq. hasta fin de carrera]
    HOMING -->|Timeout 2s| FALLBACK[Girar 95° derecha]
    HOMING -->|Fin de carrera| CENTER[Girar 95° derecha]
    FALLBACK --> MOTOR_OFF[stepper_motor_power_off]
    CENTER --> MOTOR_OFF
    MOTOR_OFF --> HOMING_DONE[Tarea homing finalizada]
```

**Orden real en `app_main`** (líneas 154–181 de `esp_vocat_rotating_base_main.c`):

| Paso | Función | Descripción |
|---|---|---|
| 1 | `nvs_flash_init()` | Persistencia para calibración magnética |
| 2 | `xSemaphoreCreateBinary()` | Sincronización fin de carrera ↔ homing |
| 3 | `stepper_motor_gpio_init()` | Configura GPIO 25–28 como salidas |
| 4 | `base_angle_limit_switch_init()` | GPIO 1 + callbacks `iot_button` |
| 5 | `boot_button_init()` | GPIO 9; pulsación larga → recalibración |
| 6 | `control_serial_init()` | UART1 @ 115200 + `uart_cmd_receive_task` |
| 7 | `control_serial_start_magnetic_detect_task()` | Reporte periódico de acoplamiento |
| 8 | `xTaskCreate(base_calibration_task)` | Homing mecánico (paralelo) |
| 9 | `magnetic_slide_switch_start()` | I2C, calibración magnética, detección |

> **I2C:** La inicialización del bus I2C y del sensor BMM150/QMC6309 ocurre dentro de `magnetic_slide_switch_start()` → `magnetometer_data_read_task`, no en `app_main`.

---

## 5. Flujo de calibración automática magnética

```mermaid
stateDiagram-v2
    [*] --> CALIBRATION_IDLE
    CALIBRATION_IDLE --> CALIBRATION_DETECTING_FIRST: Sin datos NVS / recalibración
    CALIBRATION_DETECTING_FIRST --> CALIBRATION_WAITING_CHANGE_1: Posición 1 estable 500ms
    CALIBRATION_WAITING_CHANGE_1 --> CALIBRATION_DETECTING_SECOND: diff > 100
    CALIBRATION_DETECTING_SECOND --> CALIBRATION_WAITING_CHANGE_2: Posición 2 estable 500ms
    note right of CALIBRATION_DETECTING_SECOND: UART 0x0082 (2ª posición OK)
    CALIBRATION_WAITING_CHANGE_2 --> CALIBRATION_DETECTING_THIRD: diff > 100
    CALIBRATION_DETECTING_THIRD --> CALIBRATION_COMPLETED: Posición 3 estable 500ms
    note right of CALIBRATION_DETECTING_THIRD: Ordenar REMOVED/UP/DOWN + NVS
    CALIBRATION_COMPLETED --> [*]: UART 0x0083
```

**Asignación automática** (tras la tercera posición):
- Valor magnético **menor** → `REMOVED`
- Valor **intermedio** → `UP`
- Valor **mayor** → `DOWN`

Constantes (`magnetic_slide_switch.h`, BMM150): `CALIBRATION_STABILITY_TIME_MS = 500`, `CALIBRATION_VALUE_DIFF_THRESHOLD = 100`.

---

## 6. Máquina de estados del interruptor magnético (perfil `base`)

Durante el modo operativo, `slide_switch_event_detect_task` evalúa el eje Z filtrado (ventana deslizante) contra los umbrales calibrados:

```mermaid
stateDiagram-v2
    [*] --> INIT
    INIT --> REMOVED: Estado inicial detectado
    REMOVED --> UP: PLACE_FROM_UP / campo aumenta
    REMOVED --> DOWN: PLACE_FROM_DOWN
    UP --> DOWN: SLIDE_DOWN
    DOWN --> UP: SLIDE_UP
    UP --> REMOVED: REMOVE_FROM_UP
    DOWN --> REMOVED: REMOVE_FROM_DOWN
    DOWN --> DOWN: SINGLE_CLICK (transitorio)
    REMOVED --> FISH: FISH_ATTACHED (Δ campo 150–200)
    FISH --> REMOVED: FISH_DETACHED
    REMOVED --> PAIRING: Campo cae > umbral
    PAIRING --> REMOVED: PAIRING_CANCELLED
```

Cada transición confirmada dispara `control_serial_send_magnetic_switch_event()` en perfil `base`, o invoca callbacks registrados en perfiles `bell`, `iphone` y `magnetic_accessory`.

---

## 7. Flujo de ejecución de acciones del motor

```mermaid
flowchart LR
    CMD[CMD 0x02 recibido] --> PARSE[Extraer action 16 bits]
    PARSE --> SWITCH{stepper_action_type_t}
    SWITCH -->|0| SHAKE[stepper_shake_head]
    SWITCH -->|1| DECAY[stepper_shake_head_decay]
    SWITCH -->|2| LOOK[stepper_look_around]
    SWITCH -->|3| BEAT[stepper_beat_swing]
    SWITCH -->|4| NUZZLE[stepper_cat_nuzzle]
    SHAKE & DECAY & LOOK & NUZZLE --> OFF[stepper_motor_power_off]
    OFF --> NOTIFY[control_serial_send_action_complete]
    BEAT --> OFF2[stepper_motor_power_off]
    OFF2 --> DONE[Sin notificación en código actual]
```

Todas las funciones de acción utilizan **half-step** (8 pasos por ciclo) con curvas de aceleración/desaceleración (`STEPPER_ACCEL_STEPS = 30`, `STEPPER_DECEL_STEPS = 30`).

---

## 8. Arquitectura del código

```
software/
├── esp_vocat_rotating_base/              # Aplicación (perfil base)
│   └── main/
│       ├── esp_vocat_rotating_base_main.c   # app_main, homing, botones
│       ├── CMakeLists.txt
│       └── idf_component.yml
├── esp_vocat_rotating_base_*_*/          # Aplicaciones demo (otros perfiles)
│   └── main/                             # Igual estructura + callback UART
└── common_components/
    ├── stepper_motor/                    # Lógica de movimiento
    │   ├── stepper_motor.c
    │   └── include/stepper_motor.h
    ├── control_serial/                   # Protocolo UART
    │   ├── control_serial.c
    │   └── include/control_serial.h
    ├── magnetic_slide_switch/            # Detección magnética multi-perfil
    │   ├── CMakeLists.txt                # Selección MAG_SW_PROFILE
    │   ├── Kconfig                       # Tipo de sensor
    │   └── profiles/
    │       ├── base/
    │       ├── bell/
    │       ├── iphone/
    │       └── magnetic_accessory/
    └── BMM150_SensorAPI/                 # Driver Bosch BMM150
```

### Tareas FreeRTOS en ejecución (magnetómetro, perfil típico)

| Tarea | Prioridad | Origen | Función |
|---|---|---|---|
| `uart_cmd_receive_task` | 12 | `control_serial_init` | Recibe y despacha comandos UART |
| `base_calibration_task` | 10 | `app_main` | Homing mecánico (se autodestruye) |
| `magnetic_detect_task` | 5 | `control_serial` | Reporte periódico acoplamiento |
| `mag_data_read_task` | 3 | `magnetic_slide_switch` | Lectura continua del sensor |
| `mag_calibration_task` | 3 | `magnetic_slide_switch` | Calibración automática |
| `slide_switch_detect_task` | 2 | `magnetic_slide_switch` | Detección de eventos |

### Comunicación entre módulos

```mermaid
flowchart LR
    MAIN[app_main] -->|init| CS[control_serial]
    MAIN -->|init| SM[stepper_motor]
    MAIN -->|start| MSS[magnetic_slide_switch]
    CS -->|comandos ángulo/acción| SM
    MSS -->|eventos UART| CS
    MSS -->|lee/escribe| NVS[(NVS)]
    MSS -->|I2C| BMM[BMM150_SensorAPI]
    CS -->|UART| HOST[ESP-VoCat]
```

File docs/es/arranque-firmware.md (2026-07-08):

# Arranque del firmware y diagramas de secuencia

> Derivado de: `esp_vocat_rotating_base_main.c`, `control_serial.c`, `magnetic_slide_switch/profiles/base/magnetic_slide_switch.c`.

[← Volver a la guía principal](../../README_ES.md) · [Arquitectura](arquitectura.md)

---

## Proceso de arranque paso a paso

### Fase 1 — Inicialización de NVS

```c
esp_err_t ret = nvs_flash_init();
if (ret == ESP_ERR_NVS_NO_FREE_PAGES || ret == ESP_ERR_NVS_NEW_VERSION_FOUND) {
    nvs_flash_erase();
    ret = nvs_flash_init();
}
```

- **Propósito:** Almacenar datos de calibración magnética (posiciones REMOVED/UP/DOWN).
- **Recuperación:** Si la partición NVS está llena o la versión cambió, se borra y reinicializa.

### Fase 2 — Sincronización de homing

- Se crea un **semáforo binario** (`s_limit_switch_semaphore`).
- El callback del fin de carrera (GPIO 1) libera el semáforo desde ISR al detectar `BUTTON_PRESS_DOWN`.

### Fase 3 — Inicialización del motor

```c
stepper_motor_gpio_init();  // GPIO 25, 26, 27, 28 como salidas, nivel bajo inicial
```

### Fase 4 — Inicialización de botones

| Botón | GPIO | Evento | Acción |
|---|---|---|---|
| Fin de carrera | 1 | `BUTTON_PRESS_DOWN` | Notifica a `base_calibration_task` |
| Boot | 9 | `BUTTON_LONG_PRESS_START` | `magnetic_slide_switch_start_recalibration()` |

### Fase 5 — Inicialización de UART

```c
control_serial_init();
// UART1, 115200 bps, 8N1, TX=GPIO29, RX=GPIO8
// Crea uart_cmd_receive_task (prioridad 12)
```

### Fase 6 — Tarea de detección de acoplamiento

```c
control_serial_start_magnetic_detect_task();
// Envía CMD 0x00 (ATTACHED) cada MAGNETIC_DETECT_INTERVAL_MS (500 ms)
```

> **Nota del código:** `magnetic_detect_task` actualmente reporta siempre `MAGNETIC_ATTACH_STATUS_ATTACHED`. Existe un `TODO` para implementar detección Hall real.

### Fase 7 — Homing mecánico (tarea paralela)

`base_calibration_task` (prioridad 10):

1. Inicializa el fin de carrera.
2. En bucle: gira **-5°** a la izquierda (`STEPPER_SPEED_FAST`) cada 2 ms.
3. Si el fin de carrera se activa → espera 200 ms → gira **+95°** → apaga motor → termina.
4. Si **timeout 2000 ms** → asume fallo mecánico → gira +95° directamente → apaga motor → termina.

### Fase 8 — Inicialización del sensor magnético

`magnetic_slide_switch_start()`:

1. **I2C** (dentro de `magnetometer_data_read_task`): SCL=GPIO3, SDA=GPIO2, 400 kHz.
2. **Inicialización del chip** BMM150 (`0x10`) o QMC6309 (`0x7C`) según `menuconfig`.
3. Crea `magnetometer_data_read_task` (lectura continua, ventana deslizante).
4. Crea `magnetometer_calibration_task`:
   - Si hay datos en NVS → carga umbrales → estado `CALIBRATION_COMPLETED`.
   - Si no → inicia máquina de estados de calibración automática (3 posiciones).
5. **Bloquea** hasta que la calibración termina (`xSemaphoreTake(s_calibration_complete_sem)`).
6. Crea `slide_switch_event_detect_task` (detección de eventos en modo operativo).

### Fase 9 — Modo operativo

Tras completar homing y calibración magnética:
- La base acepta comandos UART de ángulo y acción.
- El interruptor magnético detecta y reporta eventos.
- El motor permanece apagado (`stepper_motor_power_off`) hasta recibir un comando.

---

## Diagrama de secuencia: recepción de comando UART

```mermaid
sequenceDiagram
    participant H as ESP-VoCat
    participant R as uart_cmd_receive_task
    participant M as stepper_motor

    H->>R: Bytes UART (trama AA 55 ...)
    R->>R: Buscar cabecera 0xAA 0x55
    alt Cabecera no encontrada
        R->>R: Descartar buffer
    else Trama incompleta
        R->>R: Esperar más datos
    else Checksum inválido
        R->>R: Descartar trama
    else CMD 0x01 (ángulo)
        R->>R: Validar rango 0-180°
        R->>R: diff = ángulo - 90
        R->>M: stepper_rotate_angle_with_accel(diff, ULTRA_FAST)
        M-->>R: OK
        R->>M: stepper_motor_power_off()
        R->>R: Actualizar ángulo absoluto interno
    else CMD 0x02 (acción)
        R->>M: Ejecutar acción según enum
        M-->>R: OK
        R->>M: stepper_motor_power_off()
        R->>H: ACTION_COMPLETE (0x02, 0x0010)
    else CMD 0x03 (recalibrar)
        R->>R: magnetic_slide_switch_start_recalibration()
    end
```

---

## Diagrama de secuencia: ejecución de acción del motor

```mermaid
sequenceDiagram
    participant H as ESP-VoCat
    participant R as uart_cmd_receive_task
    participant M as stepper_motor
    participant GPIO as GPIO 25-28

    H->>R: AA 55 00 03 02 00 02 04 (LOOK_AROUND)
    R->>R: Parsear action = 0x0002
    R->>M: stepper_look_around(35, 35, 10, 600, 600, 800)
    loop Half-step con aceleración
        M->>GPIO: Secuencia CW/CCW 8 pasos
        M->>M: esp_rom_delay_us(delay)
    end
    M-->>R: Acción finalizada
    R->>M: stepper_motor_power_off()
    R->>H: AA 55 00 03 02 00 10 12 (ACTION_COMPLETE)
```

---

## Diagrama de secuencia: detección de evento magnético

### Perfil `base` (envío directo)

```mermaid
sequenceDiagram
    participant S as Sensor BMM150
    participant RD as mag_data_read_task
    participant DT as slide_switch_event_detect_task
    participant CS as control_serial
    participant H as ESP-VoCat

    loop Cada MAG_SAMPLE_PERIOD_MS (5ms)
        RD->>S: Leer mag_x, mag_y, mag_z (I2C)
        RD->>RD: Ventana deslizante + filtro
    end
    DT->>DT: Comparar Z con umbrales REMOVED/UP/DOWN
    DT->>DT: Detectar transición (ej. SLIDE_DOWN)
    DT->>CS: control_serial_send_magnetic_switch_event(SLIDE_DOWN)
    CS->>H: AA 55 00 03 03 00 01 04
```

### Perfiles demo (`bell`, `iphone`, `magnetic_accessory`)

```mermaid
sequenceDiagram
    participant DT as slide_switch_detect_task
    participant CB as magnetic_slide_switch_event_cb
    participant CS as control_serial
    participant H as ESP-VoCat

    DT->>DT: Detectar evento
    DT->>CB: callback(event)
    CB->>CS: control_serial_send_magnetic_switch_event(event)
    CS->>H: Trama UART con código de evento
```

> En proyectos demo, el callback se registra en `app_main` **antes** de `magnetic_slide_switch_start()`:
> `magnetic_slide_switch_register_callback(magnetic_slide_switch_event_cb);`

---

## Diagrama de secuencia: calibración automática

```mermaid
sequenceDiagram
    participant U as Usuario
    participant CT as magnetometer_calibration_task
    participant NVS as NVS Flash
    participant CS as control_serial
    participant H as ESP-VoCat

    CT->>NVS: ¿Datos de calibración guardados?
    alt Sin datos / recalibración
        CT->>CS: MAG_SWITCH_CALIB_START (0x0081)
        CS->>H: Notificar inicio
        U->>U: Mantener posición 1 (~500ms)
        CT->>CT: CALIBRATION_DETECTING_FIRST → registrar pos. 1
        U->>U: Mover a posición 2 (diff > 100)
        CT->>CT: CALIBRATION_DETECTING_SECOND → registrar pos. 2
        CT->>CS: MAG_SWITCH_CALIB_FIRST_DONE (0x0082)
        CS->>H: Segunda posición OK
        U->>U: Mover a posición 3 (diff > 100)
        CT->>CT: CALIBRATION_DETECTING_THIRD → registrar pos. 3
        CT->>CT: Ordenar → REMOVED / UP / DOWN
        CT->>NVS: Guardar umbrales
        CT->>CS: MAG_SWITCH_CALIB_COMPLETE (0x0083)
        CS->>H: Calibración completa
    else Datos existentes
        CT->>NVS: Cargar umbrales
        CT->>CT: CALIBRATION_COMPLETED
    end
    CT->>CT: xSemaphoreGive(calibration_complete_sem)
    Note over CT: slide_switch_event_detect_task puede iniciar
```

---

## Tiempos de arranque estimados

| Fase | Duración típica | Bloqueante |
|---|---|---|
| NVS + GPIO + UART | < 100 ms | Sí (secuencial en `app_main`) |
| Homing motor | 1–5 s (depende de posición) | No (tarea paralela) |
| Calibración magnética (1ª vez) | 15–60 s (acción del usuario) | **Sí** (`magnetic_slide_switch_start` bloquea hasta calibrar) |
| Calibración magnética (NVS existente) | < 1 s | Sí (carga NVS) |
| Modo operativo | — | Tras calibración magnética |

> **Importante:** `magnetic_slide_switch_start()` bloquea `app_main` hasta completar la calibración magnética. El homing del motor se ejecuta en paralelo durante este bloqueo.

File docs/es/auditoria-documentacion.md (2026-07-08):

# Auditoría de documentación — archivos en chino

> **Fecha:** 2026-07-08  
> **Alcance:** todos los Markdown en chino del repositorio, comparados con `README_ES.md`, `docs/es/` y documentación en inglés.  
> **Acción:** limpieza completada el 2026-07-08 — **7 archivos en chino eliminados**.

[← Índice documentación](README.md) · [Auditoría hardware](auditoria-hardware.md)

---

## 1. Inventario de archivos en chino

| # | Archivo | Líneas (aprox.) | Tipo |
|---|---|---|---|
| 1 | `README_CN.md` | 129 | README raíz |
| 2 | `magnetic_sensing_interaction_solution_zh.md` | 44 | Guía magnética |
| 3 | `software/esp_vocat_rotating_base/README_CN.md` | 349 | README firmware |
| 4 | `software/esp_vocat_rotating_base_bell_event_detection/README_CN.md` | 350 | README firmware |
| 5 | `software/esp_vocat_rotating_base_iphone_detection/README_CN.md` | 349 | README firmware |
| 6 | `software/esp_vocat_rotating_base_magnetic_accessory_detection/README_CN.md` | 350 | README firmware |
| 7 | `software/common_components/BMM150_SensorAPI/README_CN.md` | 175 | README componente tercero |

**Total:** 7 archivos Markdown en chino.

**Nota:** `docs/7726, 2155.txt` contiene texto en chino (exportación OSHWHUB) pero no es README; se conserva como fuente de hardware, fuera del alcance de esta limpieza.

---

## 2. Tabla de auditoría por archivo

| Archivo | ¿Migrado al español? | ¿Info exclusiva? | Enlaces activos | ¿Conservar? | Acción recomendada |
|---|---|---|---|---|---|
| `README_CN.md` | **Sí** — contenido equivalente en `README_ES.md` (más completo) y `README.md` | No — duplicado de `README.md` en chino; enlaces Bilibili/Gitee/OSHWHUB ya en `README_ES.md` | Sí (internos y externos) | **No** (si se mantiene inglés) | **Eliminar** tras actualizar `README.md` |
| `magnetic_sensing_interaction_solution_zh.md` | **Sí** — equivalente a `magnetic_sensing_interaction_solution_es.md` | No | Sí | **No** | **Eliminar** |
| `software/.../README_CN.md` (×4) | **Parcial** — lo esencial está en `docs/es/`; detalle extenso duplicado en `README.md` (EN) | No respecto al CN; sí hay detalle no traducido al ES pero **presente en inglés** (API motor, rangos magnéticos BMM150, historial versiones) | Sí | **No** (si se mantiene `README.md` EN) | **Eliminar** los 4 archivos |
| `BMM150_SensorAPI/README_CN.md` | **No** al español — traducción del `README.md` EN del componente | No — duplicado del README inglés del driver Bosch/Espressif | Sí | **No** (si se mantiene EN) | **Eliminar** |

---

## 3. Comparativa de cobertura

### 3.1 README raíz

| Contenido | README_CN | README.md (EN) | README_ES |
|---|---|---|---|
| Descripción del proyecto | ✓ | ✓ | ✓ |
| Estructura del repo | ✓ | ✓ | ✓ (actualizada) |
| Demos / perfiles | ✓ | ✓ | ✓ + enlaces `docs/es/` |
| UART / comandos | Enlace a README_CN firmware | Enlace a README EN firmware | `docs/es/tablas-referencia.md` |
| Hardware / fabricación | Enlace OSHWHUB | Enlace OSHWHUB | `docs/es/BOM.md`, `guia-ensamblaje.md`, etc. |
| CSI, Bilibili, Gitee | ✓ | ✓ | ✓ |

**Conclusión:** `README_ES.md` es **superset** de `README_CN.md` para uso en español.

### 3.2 README firmware (`software/*/README_CN` vs `README_ES`)

| Contenido | README_CN (~350 líneas) | README_ES (~50 líneas) | `docs/es/` |
|---|---|---|---|
| Compilar / flashear | ✓ | ✓ | `arranque-firmware.md` |
| GPIO / UART | ✓ | Enlaces | `tablas-referencia.md` |
| Ejemplos hex UART | ✓ extenso | Enlace | `tablas-referencia.md` (principal) |
| Arquitectura tareas | ✓ | Enlace | `arquitectura.md`, `arranque-firmware.md` |
| Calibración magnética | ✓ detallado | Enlace | `arquitectura.md` |
| API `stepper_*` con firmas | ✓ | — | Mención en `arquitectura.md`, no firmas completas |
| Rangos magnéticos BMM150 (709/1383/2047) | ✓ | — | **No migrado** |
| Parámetros rendimiento | ✓ | — | `tablas-referencia.md` § rendimiento |
| FAQ extendido | ✓ | — | `troubleshooting.md` (cobertura similar) |
| Historial de versiones | ✓ | — | **No migrado** |

**Conclusión:** los README_CN de firmware son **traducción paralela** de `README.md` (inglés), no de `README_ES.md`. Para español, la documentación operativa está en `docs/es/`. Quedan **brechas menores** (firmas API motor, rangos de campo magnético, changelog firmware) disponibles en inglés en `software/*/README.md`.

### 3.3 Sensado magnético

| Archivo | Líneas | Equivalente ES |
|---|---|---|
| `magnetic_sensing_interaction_solution_zh.md` | 44 | `magnetic_sensing_interaction_solution_es.md` (45) + `docs/es/perfiles.md` |

**Contenido:** migrado al 100 %.

### 3.4 BMM150_SensorAPI

| Archivo | Notas |
|---|---|
| `README_CN.md` | Traducción de `README.md` (adaptador AUX BMI270); **no usado directamente** por la base ESP-VoCat (BMM150 vía I2C directo) |
| `README.md` (EN) | Conservar como referencia del componente |

---

## 4. ¿Es autosuficiente la documentación en español?

| Área | Autosuficiente | Notas |
|---|---|---|
| Guía del proyecto | **Sí** | `README_ES.md` |
| Arquitectura / UART / GPIO | **Sí** | `docs/es/` |
| Fabricación hardware | **Sí** | BOM, lista compra, ensamblaje, auditoría HW |
| Firmware — uso diario | **Sí** | Compilar, perfiles, troubleshooting |
| Firmware — referencia API motor | **Parcial** | Firmas en `README.md` EN; opcional migrar a `docs/es/extender-proyecto.md` |
| Rangos calibración BMM150 (709…) | **Parcial** | Solo en README EN/CN; no crítico para operación |
| Driver BMM150 AUX | **N/A** | Componente auxiliar; EN suficiente |

**Veredicto:** la documentación en español es **autosuficiente para usar, fabricar y depurar** el proyecto. Eliminar archivos chinos **no rompe** ese flujo si se conserva `README.md` en inglés para detalle firmware residual.

---

## 5. Referencias internas a archivos chinos
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

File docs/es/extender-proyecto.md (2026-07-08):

# Cómo extender el proyecto

> Basado en la estructura real de `common_components/` y el mecanismo `MAG_SW_PROFILE`.

[← Volver a la guía principal](../../README_ES.md) · [Perfiles](perfiles.md)

---

## 1. Crear un nuevo perfil magnético

### Paso 1 — Copiar un perfil existente

```bash
cd software/common_components/magnetic_slide_switch/profiles
cp -r bell mi_perfil
```

### Paso 2 — Definir eventos en el header

Editar `profiles/mi_perfil/include/magnetic_slide_switch.h`:
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

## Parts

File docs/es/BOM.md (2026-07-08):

# BOM — Lista de materiales (ESP-VoCat Base V1.0)

> **Fuentes:** esquemáticos PDF en `hardware/`, exportación parcial OSHWHUB en `docs/7726, 2155.txt`, PCB PDF (designadores).  
> **Versión hardware:** V1.0 (2026-03-11)  
> **BOM completa en CSV:** no incluida en el repositorio → descargar en [OSHWHUB esp-echoear-base](https://oshwhub.com/esp-college/esp-echoear-base)

[← Guía de fabricación](guia-ensamblaje.md) · [Lista de compra](lista-compra.md) · [Hardware](hardware.md)

---

## Leyenda de estado

| Estado | Significado |
|---|---|
| **Confirmado** | Valor/designador extraído del esquemático PDF |
| **MPN parcial** | Código de fabricante parcial desde OSHWHUB (exportación incompleta) |
| **Pendiente de verificar** | Dato no presente en el repositorio; verificar en OSHWHUB o esquemático interactivo |

---

## Main Board (`ESP-VoCat-Base-MainBoard-V1_0`)

### Circuitos integrados y módulos

| Designador | Componente | Valor | Encapsulado | Fabricante | MPN / referencia | Alternativas | Cant. | Función | Estado |
|---|---|---|---|---|---|---|---|---|---|
| `U1` | Módulo Wi-Fi MCU | ESP32-C61-WROOM-1 | Módulo SMD | **Espressif** | ESP32-C61-WROOM-1-N8R2 (OSHWHUB) | ESP32-C61-WROOM-1U | 1 | MCU principal, UART, I2C, ADC, GPIO | Confirmado |
| `U2` | Regulador buck DC-DC | TLV62569 | SOT-23-6 (`DBVR`) | Texas Instruments | TLV62569DBVR | **Pendiente de verificar** — buck 5V→3,3V equivalente | 1 | Alimentación 3,3 V | Confirmado |
| `U3` | Interruptor de potencia USB | TPS2051B | SOT-23-5 (`DBVR`) | Texas Instruments | TPS2051BDBVR | TPS2051C, AP2161 (verificar pinout) | 1 | Limitación 500 mA a `VBUS_OUT` | Confirmado |
| `U4` | Driver Darlington | ULN2003A | DIP-16 / SOP-16 | TI / múltiples | ULN2003A | ULN2003AN, TD62783 | 1 | Driver motor paso a paso | Confirmado |
| `U5` | Magnetómetro 3 ejes | BMM150 | **WLCSP** (OSHWHUB) | Bosch Sensortec | BMM150 | — (excluyente con U6) | 1 | Sensor magnético I2C 0x10 | Confirmado |
| `U6` | Magnetómetro 3 ejes (alt.) | QMC6309 | **WLCSP** (OSHWHUB) | QST | QMC6309 | — (excluyente con U5) | 1 | Sensor magnético I2C 0x7C | Confirmado |
| `U7` | Sensor Hall lineal | SS49E | — | Honeywell | SS49E | SS49E-T, otros Hall lineales (verificar curva ADC) | 1 | Detección magnética analógica | Confirmado |
| `Q1` | MOSFET N | AO3400A | SOT-23 | AOS / Alpha & Omega | AO3400A | 2N7002, SI2302 (verificar Id/Vgs) | 1 | Control / nivel WS2812B | Confirmado |

### Conectores y electromecánicos

| Designador | Componente | Valor / modelo PCB | Encapsulado | Fabricante | MPN | Alternativas | Cant. | Función | Estado |
|---|---|---|---|---|-----|---|---|---|---|
| `USB1` | USB Type-C receptáculo | TYPE-C 16PIN 2MD(073) | SMD 16P | **Pendiente de verificar** | — | USB-C 16P con CC (ver OSHWHUB) | 1 | Entrada 5 V + USB debug | Confirmado (ref. PCB) |
| `CN1` | Conector motor | 1.25-5P WT | Wafer 1,25 mm 5P | **Pendiente de verificar** | — | Conector 1,25 mm 5P ángulo recto | 1 | Cable motor 24BYJ48 | Confirmado (ref. PCB) |
| `CN3` | Conector Sub Board | WAFER-SHB1.0-5PLT-W1-P | FFC 1,0 mm 5P | **Pendiente de verificar** | — | SH1.0 5P wafer | 1 | Cable plano a Sub Board | Confirmado (ref. PCB) |
| `CN2` | Header I2C expansión | HC-1.25-4PLT | Pin header 1,25 mm 4P | **Pendiente de verificar** | — | Header 2,54 mm (adaptar PCB) | 1 | Expansión I2C | Confirmado (ref. PCB) |
| `CN4` | Header RGB | HC-1.25-3PLT | Pin header 1,25 mm 3P | **Pendiente de verificar** | — | — | 1 | Expansión WS2812B | Confirmado (ref. PCB) |
| `H1` | Header LD2402 | PZ254V-11-05P | Header 2,54 mm 5P | **Pendiente de verificar** | — | — | 1 | Interfaz radar LD2402 (opcional) | Confirmado (ref. PCB) |
| `BOOT` | Pulsador táctil | GT-TC072A-H060-L1 | THT/SMD 6×6 mm | G-Switch (ref. esquemático) | GT-TC072A-H060-L1 | Tact switch 6×6 mm activo bajo | 1 | Botón Boot → GPIO9 | Confirmado |
| `LED1` | LED indicador | — | **Pendiente de verificar** | — | — | LED 0603/0805 | 1 | Indicador visual | Pendiente de verificar |

### Diodos

| Designador | Componente | Valor | Encapsulado | Fabricante | MPN | Alternativas | Cant. | Función | Estado |
|---|---|---|---|---|-----|---|---|---|---|
| `D1`–`D3` | Diodo protección USB | — | **Pendiente de verificar** | — | — | ESD USB (ej. USBLC6) si aplica | 3 | Protección / ruta USB | Pendiente de verificar |
| `D4`–`D5` | Diodo (circuito Boot) | — | **Pendiente de verificar** | — | — | — | 2 | Circuito botón Boot | Pendiente de verificar |
| `D6`–`D7` | Diodo (rama VBUS) | — | **Pendiente de verificar** | — | — | — | 2 | Protección / polaridad VBUS | Pendiente de verificar |

### Inductor

| Designador | Componente | Valor | Encapsulado | Fabricante | MPN | Alternativas | Cant. | Función | Estado |
|---|---|---|---|---|-----|---|---|---|---|
| `L1` | Inductor power | 2,2 µH | **Pendiente de verificar** | — | — | Inductor 2,2 µH ≥ rated current DC-DC | 1 | Buck TLV62569 | Confirmado (valor) |

### Condensadores — Main Board

| Designador | Valor | Encapsulado (OSHWHUB) | MPN (OSHWHUB) | Cant. | Función | Estado |
|---|---|---|---|---|---|---|
| `C1`, `C3`, `C8` | 10 µF | C0603 | CL10A106K (Samsung) | 3 | Bulk / desacoplo 3,3 V | MPN parcial |
| `C2`, `C4`, `C5`, `C6`, `C10`, `C11`, `C12`, `C13`, `C14` | 100 nF | C0402 | CL05B104KB8NNNC (CL05B104K en export.) | 9 | Desacoplo por IC / ruta | MPN parcial |
| `C9` | 1 µF | C0402 | CL05A105KA5NQNC (CL05A105K en export.) | 1 | Desacoplo | MPN parcial |
| `C7` | 22 µF | **Pendiente de verificar** | — | 1 | Entrada/salida DC-DC / VBUS | Confirmado (valor) |
| `C15` | 10 nF | **Pendiente de verificar** | — | 1 | Filtro Hall SS49E | Confirmado (valor) |

### Resistencias — Main Board

| Designador | Valor | Encapsulado (OSHWHUB) | MPN (OSHWHUB) | Cant. | Función | Estado |
|---|---|---|---|---|---|---|
| `R1`, `R4` | 5,1 kΩ | **Pendiente de verificar** | — | 2 | Resistencias CC USB Type-C | Confirmado (valor) |
| `R2` | 100 kΩ | **Pendiente de verificar** | — | 1 | Retroalimentación DC-DC (FB) | Confirmado (valor) |
| `R3`, `R6` | 10 kΩ | R0402 | 0402WGF1002 (0402WGF1 truncado) | 2 | Circuito EN / GPIO9 | MPN parcial |
| `R5` | 22,1 kΩ | **Pendiente de verificar** | — | 1 | Retroalimentación DC-DC (FB) | Confirmado (valor) |
| `R7` | 1 kΩ | **Pendiente de verificar** | — | 1 | — | Confirmado (valor) |
| `R8`, `R9` | 4,7 kΩ | R0402 | 0402WGF4700 (0402WGF4 truncado) | 2 | Limitación corriente LED1 | MPN parcial |
| `R10`, `R11` | 10 kΩ | R0402 | 0402WGF1002 | 2 | Polarización Q1 (RGB) | MPN parcial |

### PCB — Main Board

| Designador | Componente | Valor | Cant. | Función | Estado |
|---|---|---|---|---|---|
| — | PCB | ESP-VoCat-Base-MainBoard-V1_0 | 1 | Placa principal | Confirmado; espesor **1,0 mm** (OSHWHUB) |

---

## Sub Board (`ESP-VoCat-Base-SubBoard-V1_0`)

| Designador | Componente | Valor | Encapsulado | Fabricante | MPN | Alternativas | Cant. | Función | Estado |
|---|---|---|---|---|-----|---|---|---|---|
| `U1` | Conector magnético pogo | 4P 2,5 mm con oreja | — | **Pendiente de verificar** | — | Pogo pin 4P según OSHWHUB | 1 | Acoplamiento magnético ESP-VoCat | Confirmado (desc. OSHWHUB) |
| `CN1` | Conector Main Board | WAFER-SHB1.0-5PLT-W1-P | FFC 1,0 mm 5P | **Pendiente de verificar** | — | Igual que CN3 Main | 1 | Enlace a Main Board | Confirmado |
| `SW1` | Interruptor de límite | TM-8764-1 | — | **Pendiente de verificar** | TM-8764-1 | Micro switch similar (activo bajo) | 1 | Fin de carrera homing | Confirmado |
| `R1` | Resistencia | 51 kΩ | **Pendiente de verificar** | — | — | 1 | Red divisor fin de carrera | Confirmado (valor) |
| `R2` | Resistencia | 100 kΩ | **Pendiente de verificar** | — | — | 1 | Red divisor fin de carrera | Confirmado (valor) |
| — | PCB | ESP-VoCat-Base-SubBoard-V1_0 | 1 | Placa secundaria | Confirmado; espesor **1,0 mm** (OSHWHUB) |

---

## Componentes externos (no en PCB)

| Ref. | Componente | Especificación | Fabricante | MPN | Cant. | Función | Fuente |
|---|---|---|---|-----|---|---|---|
| `M1` | Motor paso a paso | 24BYJ48 DC 5V | Múltiples | 24BYJ48 | 1 | Actuador rotación | OSHWHUB + esquemático |
| — | Cable motor | Incluido con 24BYJ48 | — | — | 1 | Motor → CN1 | Implícito |
| `J1` | Rodamiento | ID 7 mm, OD 11 mm, H 3 mm | Múltiples | **Pendiente de verificar** | 1 | Soporte plato giratorio | OSHWHUB |
| `FFC1` | Cable plano | SH 1,0 mm, 5P, 60 mm, misma dirección | — | — | 1 | Main ↔ Sub | OSHWHUB |
| `MAG1` | Imán | D10×1,5 mm | — | — | 2 | Acoplamiento en carcasa | OSHWHUB |
| `MAG2` | Imán | D6×5 mm | — | — | 1 | Deslizador magnético 3D | OSHWHUB |
| `LD1` | Radar (opcional) | LD2402 | Hi-Link / Espressif ref. | LD2402 | 1 | Detección presencia (no en firmware base) | OSHWHUB + esquemático |
| `LED_STRIP` | Tira LED (opcional) | WS2812B | Múltiples | WS2812B | 1 | RGB expansión (no en firmware base) | Esquemático |

---

## Tornillería (OSHWHUB)

| Especificación | Cant. | Uso |
|---|---|-----|
| Tornillo M4×5 mm | 2 | Fijación motor |
| Tornillo M2×4 mm | 2 | Fijación Main Board a carcasa |
| Tornillo M2×3 mm | 2 | Cubierta superior plato giratorio |

---

## Resumen de cantidades por categoría

| Categoría | Ítems únicos (aprox.) | Notas |
|---|---|---|
| IC / módulo | 8–9 | Soldar U5 **o** U6, no ambos |
| Conectores | 7 + pogo | — |
| Pasivos SMD | ~25 | Ver tablas R/C/L |
| Diodos / LED | 8+ | Mayoría pendiente MPN |
| PCB | 2 | Pedir en JLCPCB/OSHWHUB |
| Mecánica / cable / imanes | 8+ | Ver lista de compra |

---

## Componentes Espressif vs reemplazables

Ver sección detallada en [lista-compra.md → Espressif vs equivalentes](lista-compra.md#espressif-vs-equivalentes-comerciales).

---

## Datos pendientes de verificar (resumen)

| Dato | Archivo donde debería aparecer |
|---|---|
| MPN completos de todos los pasivos | BOM CSV en [OSHWHUB](https://oshwhub.com/esp-college/esp-echoear-base) |
| MPN diodos D1–D7 | Esquemático interactivo EasyEDA (no en PDF extraído) |
| Tipo exacto LED1 (color, corriente) | Esquemático / BOM OSHWHUB |
| MPN inductor L1 | BOM OSHWHUB |
| MPN conectores USB1, CN1–CN4, H1 | BOM OSHWHUB |
| MPN pogo pin U1 Sub Board | BOM OSHWHUB |
| MPN rodamiento | OSHWHUB lista de compra |
| Resistencias pull-up I2C (si existen) | Netlist EasyEDA |

---

> **Auditoría:** ver [auditoria-hardware.md](auditoria-hardware.md) para MPN pendientes, contradicciones y checklist.

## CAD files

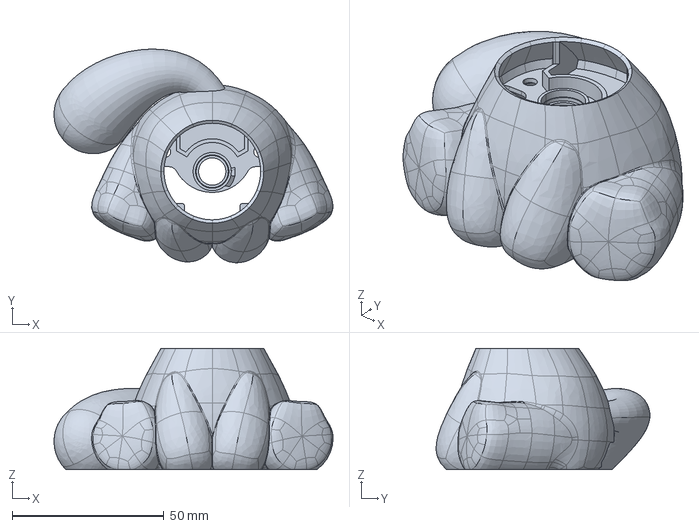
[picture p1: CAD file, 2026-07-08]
3D_models/ESP-VoCat_catbase_20251128.stp
92.0 x 70.5 x 40.0 mm

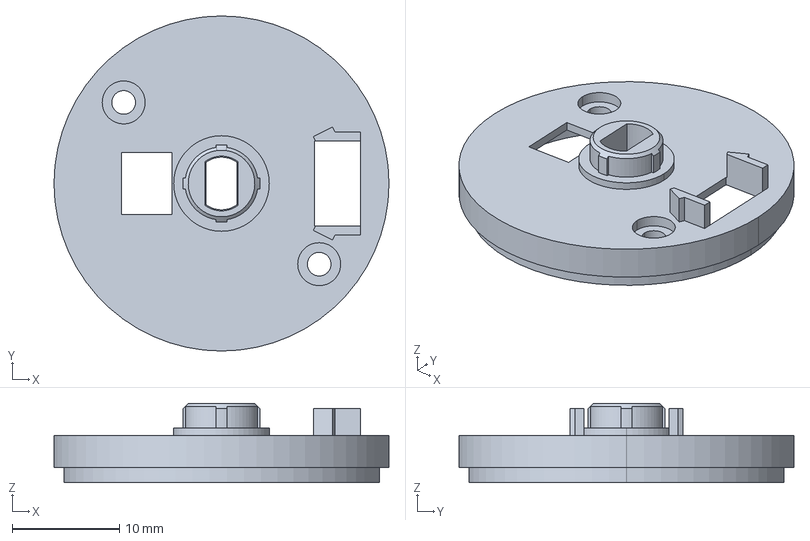
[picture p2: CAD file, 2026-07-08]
3D_models/ESP-VoCat_catbase_platform_btm_20251128.stp
31.2 x 31.2 x 7.40 mm

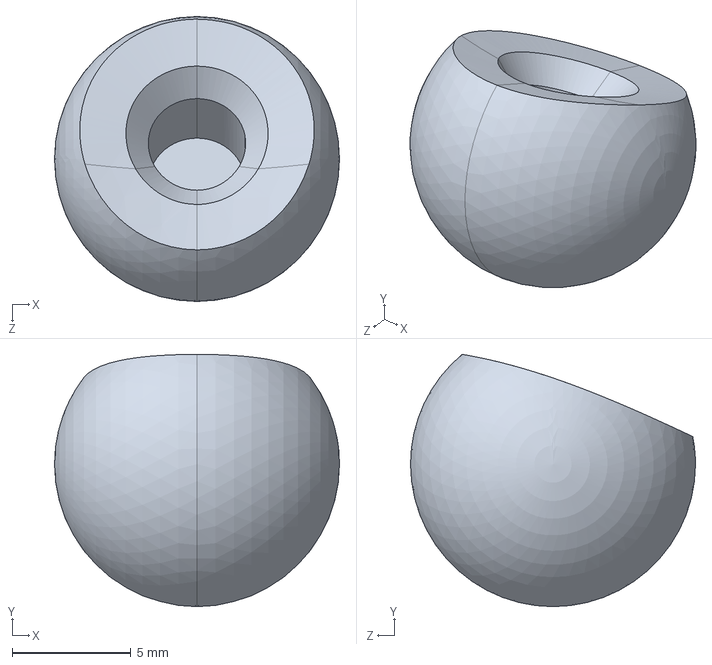
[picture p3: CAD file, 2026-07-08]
3D_models/ESP-VoCat catbase ball only 2025-11-22.STEP
12.0 x 10.6 x 12.0 mm

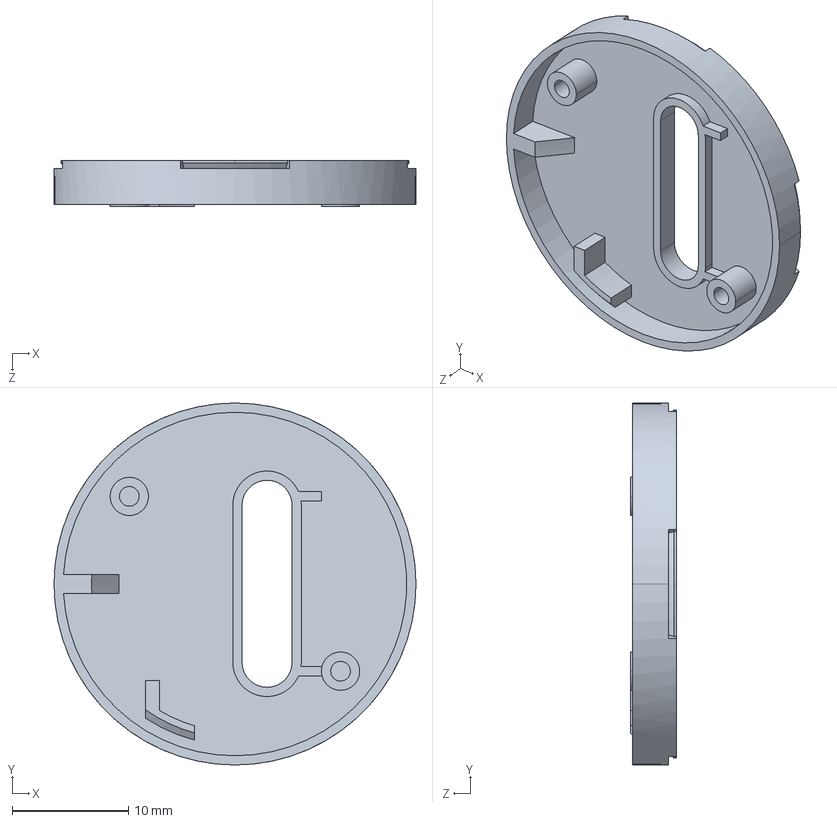
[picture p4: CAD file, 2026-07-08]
3D_models/ESP-VoCat catbase platform top 2025-11-22.STEP
31.2 x 31.2 x 4.00 mm

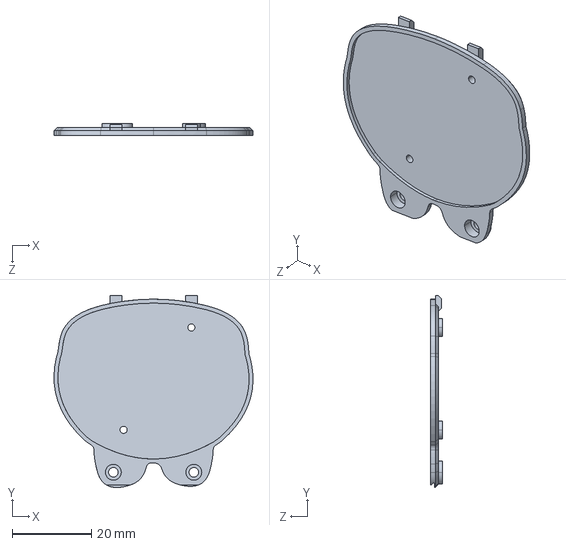
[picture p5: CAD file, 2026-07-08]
3D_models/ESP-VoCat catbase cover 2025-11-22.STEP
50.2 x 48.4 x 3.00 mm

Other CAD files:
3D_models/ESP-VoCat_catbase_platform_btm_20251128.3mf

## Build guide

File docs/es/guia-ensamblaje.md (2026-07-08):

# Guía de ensamblaje — ESP-VoCat Base V1.0

> Orden recomendado para montar una réplica funcional.  
> Referencias: [BOM](BOM.md) · [Lista de compra](lista-compra.md) · [Hardware](hardware.md) · pasos 1–10 en `docs/7726, 2155.txt` (OSHWHUB).

---

## Herramientas recomendadas

| Herramienta | Uso |
|---|-----|
| Estación de soldadura / hot air | SMD en Main y Sub Board |
| Multímetro | Comprobar 3,3 V y continuidad |
| Destornilladores M2 / M4 | Mecánica |
| Cable USB-C | Alimentación y flasheo |
| Impresora 3D FDM | Carcasa (archivos STEP en `3D_models/`) |
| Pinzas, cinta kapton | Cable FFC e imanes |

---

## Impresión 3D

Los archivos STEP **no contienen** material, orientación, soportes, altura de capa ni relleno. Los parámetros siguientes deben tomarse de OSHWHUB o determinarse por prueba.

### Correspondencia piezas OSHWHUB ↔ archivos del repositorio

| # OSHWHUB | Pieza (OSHWHUB) | Archivo en `3D_models/` |
|---|---|---|
| 1 | Carcasa exterior | `ESP-VoCat_catbase_20251128.stp` |
| 2 | Cubierta inferior carcasa | `ESP-VoCat_catbase_platform_btm_20251128.stp` |
| 3 | Cubierta plato giratorio | `ESP-VoCat catbase cover 2025-11-22.STEP` |
| 4 | Tapa inferior plato | `ESP-VoCat catbase platform top 2025-11-22.STEP` |
| 8 | Interruptor deslizante magnético | `ESP-VoCat catbase ball only 2025-11-22.STEP` |

| Archivo (`3D_models/`) | Pieza | Material recomendado | Orientación | Soportes | Altura capa | Relleno | Estado |
|---|---|---|---|---|---|---|---|
| `ESP-VoCat_catbase_20251128.stp` | Base / carcasa principal | **Pendiente de verificar** — típ. PLA/PETG | **Pendiente de verificar** | **Pendiente de verificar** | **Pendiente de verificar** | **Pendiente de verificar** | Sin datos en STEP |
| `ESP-VoCat_catbase_platform_btm_20251128.stp` | Plataforma inferior plato | **Pendiente de verificar** | **Pendiente de verificar** | **Pendiente de verificar** | **Pendiente de verificar** | **Pendiente de verificar** | Sin datos en STEP |
| `ESP-VoCat catbase platform top 2025-11-22.STEP` | Plataforma superior plato | **Pendiente de verificar** | **Pendiente de verificar** | **Pendiente de verificar** | **Pendiente de verificar** | **Pendiente de verificar** | Sin datos en STEP |
| `ESP-VoCat catbase cover 2025-11-22.STEP` | Cubierta | **Pendiente de verificar** | **Pendiente de verificar** | **Pendiente de verificar** | **Pendiente de verificar** | **Pendiente de verificar** | Sin datos en STEP |
| `ESP-VoCat catbase ball only 2025-11-22.STEP` | Bola / inserto mecánico | **Pendiente de verificar** | **Pendiente de verificar** | **Pendiente de verificar** | **Pendiente de verificar** | **Pendiente de verificar** | Sin datos en STEP |

**Sugerencia provisional (no oficial):** PLA o PETG, capa 0,2 mm, relleno 20–30 % en piezas estructurales; orientar de modo que las superficies de asiento del PCB queden planas (verificar en slicer). Confirmar en [OSHWHUB](https://oshwhub.com/esp-college/esp-echoear-base).

**Imanes en piezas 3D:** insertar imán D10×1,5 mm (×2) y D6×5 mm (×1) según alojamientos del modelo; fijar con adhesivo si el ajuste es holgado.

---

## Fase 1 — Electrónica

### 1.1 Main Board (SMT)

Seguir orden típico SMT (de menor a mayor altura):

1. Soldar pasivos 0402/0603: resistencias y condensadores según [BOM](BOM.md).
2. Soldar `U2` (TLV62569), `U3` (TPS2051B), `Q1` (AO3400A).
3. Soldar **solo uno**: `U5` (BMM150) **o** `U6` (QMC6309) — no ambos.
4. Soldar `U7` (SS49E), `U4` (ULN2003A).
5. Soldar `USB1`, conectores `CN1`, `CN3`, `CN2`, `CN4`, `H1`.
6. Soldar `BOOT`, `LED1`, diodos `D1`–`D7`, inductor `L1`.
7. Soldar `U1` (ESP32-C61-WROOM-1) al final (mayor altura / sensible a calor).

**Comprobaciones antes de energizar:**

- Sin cortocircuitos entre `VBUS` y `GND`.
- `VCC_3V3` estable (~3,3 V) con USB conectado.
- Resistencias CC `R1`/`R4` (5,1 kΩ) presentes en USB-C.

### 1.2 Sub Board

1. Soldar `R1` (51 kΩ), `R2` (100 kΩ).
2. Soldar `SW1` (TM-8764-1) con orientación que permita accionamiento mecánico del fin de carrera.
3. Soldar `U1` (pogo pin 4P) y `CN1` (wafer SH1.0 5P).
4. **Orientación pogo pin (OSHWHUB):** el extremo marcado en rojo debe quedar en el **mismo lado** que el círculo blanco impreso en la PCB Sub Board.
5. **No** conectar aún el cable FFC a la Main Board.

> **Nota WLCSP:** los magnetómetros BMM150/QMC6309 usan encapsulado WLCSP, difícil de soldar a mano. OSHWHUB recomienda servicio SMT para usuarios sin experiencia.

### 1.3 Ensamblaje eléctrico Main ↔ Sub

1. Crimpolar / insertar cable FFC **SH1.0 5P 60 mm** en `CN3` (Main) y `CN1` (Sub).
2. Verificar pinout: `GND`, `VBUS`, `TX`, `RX`, `ANGLE_LIMIT_SW` (ver [hardware.md](hardware.md)).

---

## Fase 2 — Motor

1. Atornillar motor **24BYJ48** a la base impresa con **2× M4×5 mm** (alojamientos en carcasa).
2. Conectar cable del motor a `CN1` (1,25 mm 5P) respetando orden de fases `IN1`–`IN4` del esquemático.
3. Comprobar que el eje gira libremente antes de montar el plato superior.

---

## Fase 3 — Final de carrera

1. Fijar Sub Board en su alojamiento mecánico (posición según modelo 3D).
2. Ajustar `SW1` para que se active cuando el plato alcanza el límite de giro (homing).
3. Con firmware cargado, comprobar que `ANGLE_LIMIT_SW` (**GPIO1**) lee **activo bajo** al pulsar el switch (ver [tablas-referencia.md](tablas-referencia.md)).

---

## Fase 4 — Sensor magnético

### Hall lineal (SS49E)

1. `U7` ya está en Main Board; posicionar imán D6×5 mm en pieza deslizadora 3D según diseño.
2. Verificar señal analógica en GPIO5 con multímetro o monitor serie (`ss49e` profile).

### Magnetómetro (BMM150 o QMC6309)

1. Confirmar que el firmware usa el perfil correcto (`bmm150` o `qmc6309`).
2. Instalar imanes D10×1,5 mm en carcasa y en dispositivo acoplado (ESP-VoCat) para acoplamiento magnético vía pogo pin.
3. Alinear Sub Board / pogo con la zona magnética del host.

---

## Fase 5 — Carcasa

Orden de montaje según OSHWHUB (pasos 1–10, `docs/7726, 2155.txt`), alineado con las fases anteriores:

| Paso | Acción |
|---|---|
| 1 | Insertar **2× imán D10×1,5 mm** en la carcasa exterior; **respetar polaridad** |
| 2 | Montar rodamiento **7×11×3 mm** en la ranura de la carcasa |
| 3 | Instalar motor **24BYJ48** con **2× M4×5 mm** — **no apretar al máximo** aún |
| 4 | Fijar **Sub Board** en la cubierta inferior del plato (`platform_btm`) |
| 5 | Montar cubierta superior del plato (`cover`) con **2× M2×3 mm** en la parte posterior |
| 6 | Insertar cable FFC **SH1.0 5P** en el conector del plato (Sub Board) |
| 7 | Acoplar plato ensamblado al eje del motor; superficie al ras con carcasa; **apretar tornillos M4** |
| 8 | Fijar **Main Board** a la carcasa con **2× M2×4 mm** |
| 9 | Conectar cable motor a `CN1` (ángulo recto, silk **Motor**) y FFC Sub→Main (conector recto en Main). **Ambos extremos del FFC en la misma dirección** — verificar antes de insertar |
| 10 | Insertar imán **D6×5 mm** en pieza deslizadora 3D (`ball only`); polaridad debe **atraer** a imanes D10×1,5 mm. Colocar sobre la base |

**Pedido PCB:** espesor **1,0 mm** (OSHWHUB).

---

## Fase 6 — Calibración inicial

### 6.1 Flasheo firmware

1. Conectar USB-C a `USB1`.
2. Flashear el proyecto adecuado desde `software/` (ver [arranque-firmware.md](arranque-firmware.md)).
3. Configurar `MAG_SW_PROFILE` según sensor soldado (`bmm150`, `qmc6309` o `ss49e`).

### 6.2 Homing y límite angular

1. Ejecutar secuencia de homing del firmware demo.
2. Verificar que el motor detiene al activar `SW1`.
3. Si el giro es incorrecto, revisar cableado motor y sentido de fases.

### 6.3 Calibración magnética

| Perfil | Acción |
|---|---|
| `bmm150` / `qmc6309` | Verificar lecturas I2C y detección de acoplamiento magnético con host |
| `ss49e` | Ajustar posición del imán D6×5 mm; revisar umbrales ADC en firmware si es necesario |

### 6.4 UART con host ESP-VoCat

1. Conectar host a través del acoplamiento pogo / magnético.
2. Probar trama UART (115200 baud) según [arquitectura.md](arquitectura.md).
3. Confirmar eventos de rotación y estado del fin de carrera.

### 6.5 Lista de verificación final

- [ ] 3,3 V y 5 V dentro de especificación
- [ ] Motor gira en ambos sentidos
- [ ] Fin de carrera responde (GPIO1)
- [ ] Sensor magnético coherente con perfil elegido
- [ ] UART operativa con host
- [ ] Calibración automática al centro tras encender (OSHWHUB paso 10)
- [ ] Sin calentamiento anormal en `U3` / `U4` tras 10 min de uso

---

## Solución de problemas de montaje

| Síntoma | Comprobar |
|---|---|
| No arranca | USB-C, `EN`, soldadura `U1`, corto VBUS |
| Motor no gira | `CN1`, `U4`, alimentación VBUS al motor |
| Homing falla | `SW1`, cable FFC, GPIO1, orientación switch |
| I2C magnetómetro NACK | Solo un de U5/U6 soldado, dirección I2C, perfil firmware |
| Hall errático | Imán D6×5, posición mecánica, `C15` |

Más detalle: [troubleshooting.md](troubleshooting.md).

---

*Parámetros 3D marcados como «Pendiente de verificar» deben confirmarse en OSHWHUB antes de una producción en serie.*

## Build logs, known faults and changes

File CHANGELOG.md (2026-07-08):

# ChangeLog

## V1.0.5 - 2026-03-30

* Refactor project layout to support multiple demo projects without branch switching.
* Add three independent demo projects under `software/`:
  * `esp_vocat_rotating_base_bell_event_detection`
  * `esp_vocat_rotating_base_iphone_detection`
  * `esp_vocat_rotating_base_magnetic_accessory_detection`
* Extract shared components to `software/common_components` and make all demo projects reuse them.
* Add profile-based compatibility for `magnetic_slide_switch` to support different event sets across demos (`base`, `bell`, `iphone`, `magnetic_accessory`).
* Update project CMake configuration and local dependency paths to match the new shared-component structure.
* Update root `README.md` and `README_CN.md` with new project structure and demo descriptions.
* Consolidate changelog management by removing per-project changelog files and keeping a single root `CHANGELOG.md`.

## V1.0.4 - 2026-01-15

* Optimize the BMM150 sampling rate.
* Optimize the single-click event detection logic of the magnetic sliding switch.

## V1.0.3 - 2025-12-24

* Add fish detached event and pairing cancelled event detection in magnetic slide switch component.
* Add initial position detection for magnetic slide switch on power-on.

## V1.0.2 - 2025-12-19

* Fix the sound source recognition angle control logic.
* Update the thresholds when using QMC6309 for the sliding switch.

## V1.0.1 - 2025-12-18

* Add feed-fish event and detection event for two bases approaching each other face-to-face (for pairing).
* Optimize single-click event detection logic.
* Optimize the automatic calibration program.
* Update README documentation.

## V1.0.0 - 2025-12-02

* First official release.
* Stepper motor control with acceleration/deceleration and predefined actions (shake head, look around, beat swing, cat nuzzle).
* Magnetic slide switch detection with auto-calibration (support Hall sensor, BMM150, QMC6309).
* UART communication protocol for angle control and event notification.
* Base auto-calibration with limit switch on startup.
* NVS storage for persistent calibration data.

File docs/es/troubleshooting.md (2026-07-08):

# Resolución de problemas (Troubleshooting)

> Basado en: documentación del repositorio, comentarios en código fuente y comportamiento observable del firmware.

[← Volver a la guía principal](../../README_ES.md) · [Arranque del firmware](arranque-firmware.md)

---

## Índice rápido

| Síntoma | Sección |
|---|---|
| Motor no encuentra Home | [§1](#1-el-motor-no-encuentra-el-home) |
| Sensor no calibra | [§2](#2-el-sensor-no-calibra) |
| Error UART | [§3](#3-error-de-comunicación-uart) |
| Sensor mal configurado | [§4](#4-configuración-incorrecta-del-sensor) |
| Fallo al compilar | [§5](#5-problemas-al-compilar-con-esp-idf) |
| Motor vibra o no gira | [§6](#6-motor-vibra-o-no-gira) |
| Clic magnético errático | [§7](#7-evento-de-clic-falso-o-no-detectado) |
| Rotación en dirección incorrecta | [§8](#8-rotación-incorrecta-en-el-primer-arranque) |

---

## 1. El motor no encuentra el Home

### Síntomas
- Log: `Calibration timeout! Limit switch not pressed within 2 seconds`
- Log: `Assuming mechanical fault, moving directly to home position`
- La base gira 95° sin haber tocado el fin de carrera.

### Causas probables (según `base_calibration_task`)

| Causa | Verificación |
|---|---|
| Fin de carrera mal conectado | GPIO 1, activo en bajo (`active_level = 0`) |
| Fin de carrera mal posicionado mecánicamente | El motor gira -5° en bucle; debe activarse en ≤ 2 s |
| Cable del interruptor roto o invertido | Medir continuidad en GPIO 1 |
| Motor no gira (sin alimentación) | Ver [§6](#6-motor-vibra-o-no-gira) |

### Solución

1. Verificar cableado del fin de carrera en GPIO 1 (ver [tablas-referencia.md](tablas-referencia.md)).
2. Confirmar que el motor gira a la izquierda durante el homing (log `Base calibration task started`).
3. Ajustar la posición mecánica del interruptor de fin de carrera.
4. Si el timeout es intencional (entorno de prueba sin fin de carrera), el firmware usa **modo fallback**: gira +95° directamente. La posición angular puede ser imprecisa.

### Referencia de código

```c
// esp_vocat_rotating_base_main.c — timeout 2000 ms
const TickType_t timeout_ticks = pdMS_TO_TICKS(2000);
// Tras fin de carrera: stepper_rotate_angle_with_accel(95.0, STEPPER_SPEED_FAST);
```

---

## 2. El sensor no calibra

### Síntomas
- La base permanece en calibración magnética indefinidamente.
- No se inicia `slide_switch_event_detect_task` (log ausente: `Calibration completed, starting slide switch detection task`).
- Log sin `MAG_SWITCH_CALIB_COMPLETE` en UART.

### Causas probables

| Causa | Verificación |
|---|---|
| Posiciones no suficientemente distintas | Diferencia entre posiciones debe ser > 100 (`CALIBRATION_VALUE_DIFF_THRESHOLD`) |
| Usuario no mantiene posición 500 ms | `CALIBRATION_STABILITY_TIME_MS = 500` |
| I2C no conectado | SCL=GPIO3, SDA=GPIO2; dirección BMM150=0x10 |
| Sensor incorrecto en menuconfig | `idf.py menuconfig` → Magnetic Slide Switch → Sensor Type |
| NVS corrupto | Borrar flash: `idf.py erase-flash` |

### Procedimiento de calibración correcto

1. Encender la base (primera vez o tras `erase-flash`).
2. **Posición 1:** dejar el deslizador inmóvil ~500 ms.
3. **Posición 2:** mover a posición claramente diferente (arriba/abajo/retirado); esperar ~500 ms.
   - La base envía `0x0082` (segunda posición OK).
4. **Posición 3:** tercera posición distinta; esperar ~500 ms.
   - La base envía `0x0083` (calibración completa).
5. Los datos se guardan en NVS automáticamente.

### Recalibración manual

- **Botón Boot:** pulsación larga en GPIO 9 (`BUTTON_LONG_PRESS_START`).
- **UART:** `AA 55 00 03 03 00 10 13` (`MAG_SWITCH_CMD_RECALIBRATE`).

---

## 3. Error de comunicación UART

### Síntomas
- ESP-VoCat no recibe eventos ni responde a movimientos.
- Log: `Checksum verification failed` o `Frame header not found`.
- Log: `Unknown command code`.

### Verificaciones

| Parámetro | Valor esperado | Fuente |
|---|---|---|
| Baudrate | 115200 | `ECHO_UART_BAUD_RATE` |
| Formato | 8N1, sin flow control | `control_serial_init()` |
| TX base | GPIO 29 | Conectar a RX del host |
| RX base | GPIO 8 | Conectar a TX del host |
| Cabecera | `0xAA 0x55` | Obligatoria en cada trama |
| Checksum | Suma de CMD + DATA | Ver [tablas-referencia.md](tablas-referencia.md) |

### Errores frecuentes

| Error | Causa |
|---|---|
| TX conectado a TX | Inversión de líneas; usar cruce TX↔RX |
| Checksum incorrecto | Recalcular: suma aritmética de bytes CMD+DATA |
| Ángulo ignorado | Valor > 180 o resultado fuera de rango 0–180° absoluto |
| Trama cortada | `LEN` no coincide con bytes reales |

### Herramientas de depuración

```bash
idf.py monitor          # Ver logs de parsing UART
```

Enviar trama de prueba (ángulo 90° = sin movimiento):
```
AA 55 00 03 01 00 5A 5B
```
Checksum: `0x01 + 0x00 + 0x5A = 0x5B`

---

## 4. Configuración incorrecta del sensor

### Síntomas
- Lecturas magnéticas erráticas o siempre cero.
- Solo funcionan SLIDE_UP/DOWN (cuando se esperan más eventos).
- Log de error I2C en `magnetometer_data_read_task`.

### Matriz de configuración

| Hardware montado | menuconfig requerido |
|---|---|
| BMM150 | `SENSOR_MAGNETOMETER` + `SENSOR_BMM150` |
| QMC6309 | `SENSOR_MAGNETOMETER` + `SENSOR_QMC6309` |
| Hall lineal | `SENSOR_LINEAR_HALL` |

### Limitaciones documentadas en código

- **Hall lineal:** solo `SLIDE_UP` / `SLIDE_DOWN` (sin calibración de 3 posiciones completa).
- **BMM150 vs QMC6309:** umbrales diferentes en cada header de perfil; no intercambiar sin recalibrar.

### Verificación I2C

| Sensor | Dirección I2C | Chip ID esperado |
|---|---|---|
| BMM150 | `0x10` | `0x32` |
| QMC6309 | `0x7C` | `0x90` |

Tras cambiar sensor en menuconfig: `idf.py fullclean build flash` y recalibrar.

---

## 5. Problemas al compilar con ESP-IDF

### Requisitos

| Requisito | Valor | Fuente |
|---|---|---|
| ESP-IDF | ≥ 5.5.0 | `idf_component.yml` |
| Target | `esp32c61` | MCU de la base |
| Dependencia | `espressif/button == 3.5.0` | `idf_component.yml` |

### Errores comunes

| Error | Solución |
|---|---|
| `Unknown MAG_SW_PROFILE` | Verificar `set(MAG_SW_PROFILE "...")` en CMakeLists del proyecto |
| Componente no encontrado | Confirmar `EXTRA_COMPONENT_DIRS` apunta a `../common_components` |
| Target incorrecto | `idf.py set-target esp32c61` antes de `build` |
| Versión IDF antigua | Actualizar a release/v5.5 o superior |
| `managed_components` faltante | Ejecutar `idf.py build` (descarga automática vía Component Manager) |

### Secuencia de compilación recomendada

```bash
cd software/esp_vocat_rotating_base
idf.py set-target esp32c61
idf.py menuconfig    # Opcional: tipo de sensor
idf.py build
idf.py -p PORT flash monitor
```

### Selección del proyecto correcto

Cada demo es un directorio independiente. No compilar desde la raíz del repositorio; entrar al subdirectorio del proyecto deseado.

---

## 6. Motor vibra o no gira

| Causa | Solución |
|---|---|
| Alimentación insuficiente | Mínimo 5 V / 1 A recomendado en documentación |
| Cableado IN1–IN4 incorrecto | GPIO 28, 27, 26, 25 respectivamente |
| Velocidad demasiado alta | Aumentar `speed_us` (valor más alto = más lento) |
| Motor bloqueado mecánicamente | Verificar engranajes y carga |

---

## 7. Evento de clic falso o no detectado

Basado en umbrales del perfil `base` con BMM150:

| Problema | Causa | Solución |
|---|---|---|
| Falso clic al deslizar | Transición rápida en eje X/Y | El firmware filtra con relación mag_x/mag_y |
| Clic no detectado | Deslizador no en posición DOWN | Requiere mag_x > mag_y |
| Clic demasiado lento | Duración > 500 ms (BMM150) | Acción rápida < 300 ms recomendada en docs |

---

## 8. Rotación incorrecta en el primer arranque

| Causa | Solución |
|---|---|
| Fin de carrera en lado incorrecto | Revisar montaje mecánico |
| Ángulo de centrado incorrecto | Valor fijo 95° en `base_calibration_task`; ajustar mecánica, no software sin validar |

---

## 9. Otros problemas documentados en código

| Problema | Detalle | Fuente |
|---|---|---|
| `BEAT_SWING` sin notificación de fin | `control_serial_send_action_complete()` comentado para `STEPPER_ACTION_BEAT_SWING` | `control_serial.c` línea ~198 |
| Detección de acoplamiento siempre ATTACHED | `magnetic_detect_task` envía siempre `0x0001`; TODO para detección real | `control_serial.c` |
| `app_main` bloqueado en calibración | `magnetic_slide_switch_start()` espera calibración antes de retornar | Diseño intencional |

---

## Registro de diagnóstico

Al reportar un problema, incluir:

1. Proyecto compilado (`esp_vocat_rotating_base` / demo).
2. Perfil (`MAG_SW_PROFILE`) y sensor (`menuconfig`).
3. Versión ESP-IDF (`idf.py --version`).
4. Log completo de `idf.py monitor` desde el arranque.
5. Trama UART enviada (hex) si aplica.

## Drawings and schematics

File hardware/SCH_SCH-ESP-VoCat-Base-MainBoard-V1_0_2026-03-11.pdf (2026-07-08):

# Type C for debug and function expansion

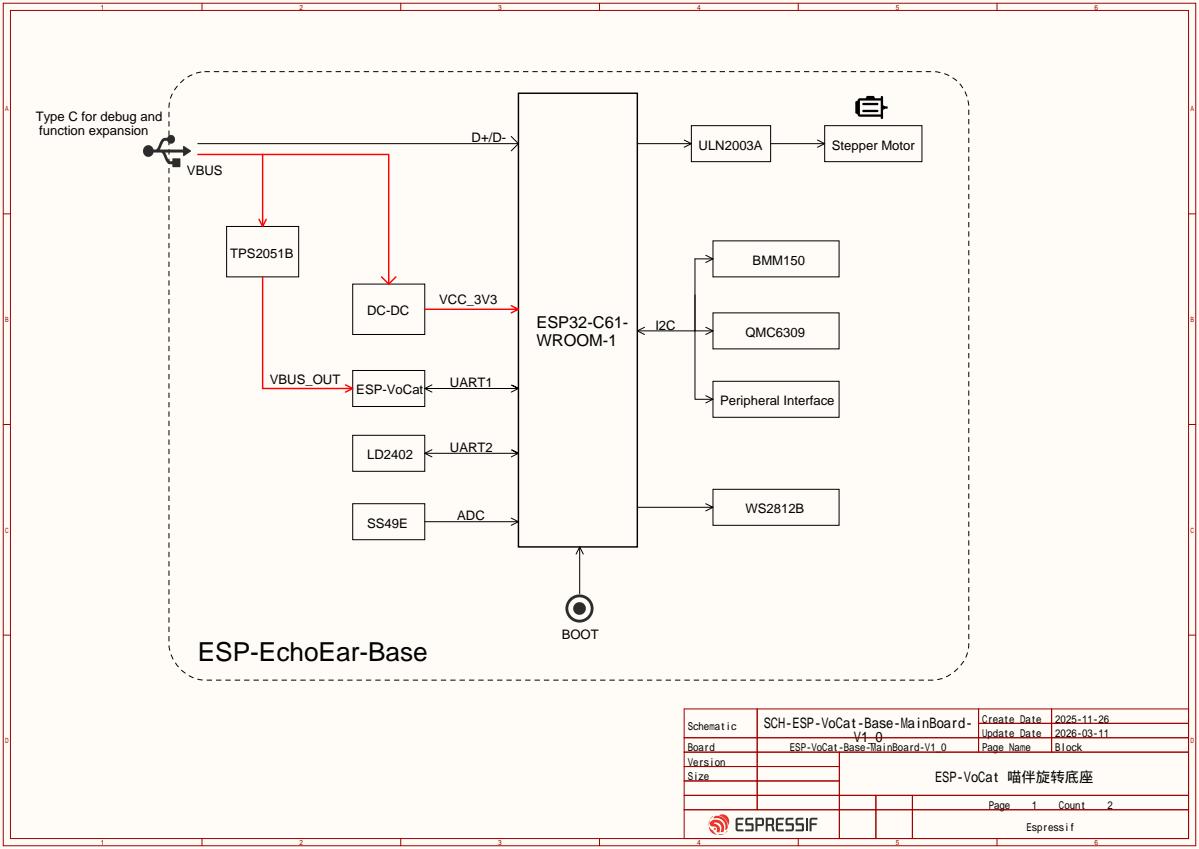
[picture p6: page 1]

Schematic | SCH-ESP-VoCat-Base-MainBoard-V1_0 | Create Date | 2025-11-26

Update Date | 2026-03-11

Board | ESP-VoCat-Base-MainBoard-V1_0 | Page Name | Block
Version | | ESP-VoCat 喵伴旋转底座
Size

Page 1 Count 2

Espressif

USB-C | DC-DC | ESP32-C61

# 500mA Current Limit

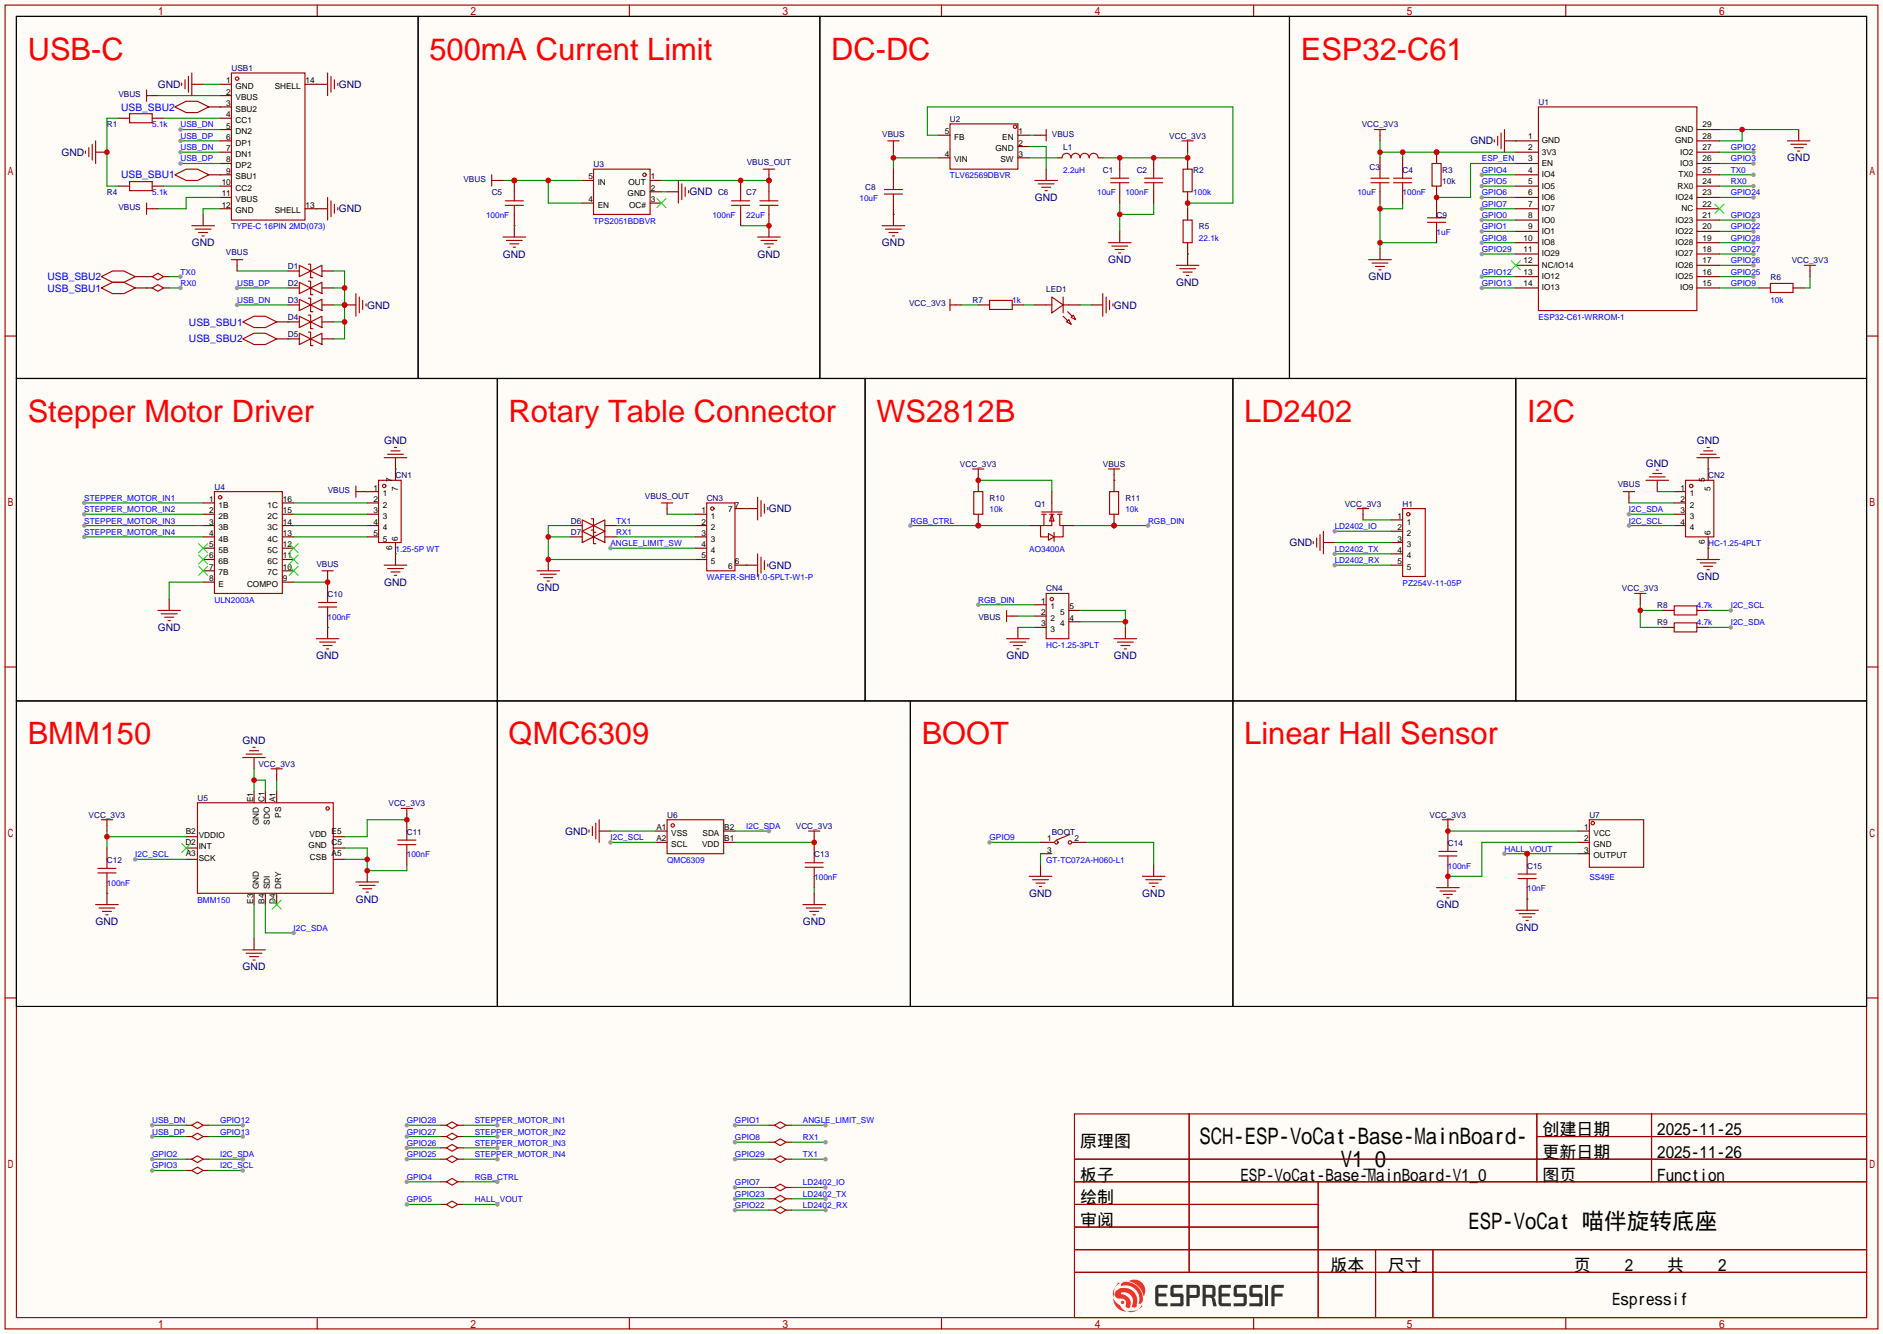
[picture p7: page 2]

原理图 | SCH-ESP-VoCat-Base-MainBoard-V1_0 | 创建日期 | 2025-11-25

更新日期 | 2025-11-26

板子 | ESP-VoCat-Base-MainBoard-V1_0 | 图页 | Function
绘制 | | ESP-VoCat 喵伴旋转底座
审阅

Espressif

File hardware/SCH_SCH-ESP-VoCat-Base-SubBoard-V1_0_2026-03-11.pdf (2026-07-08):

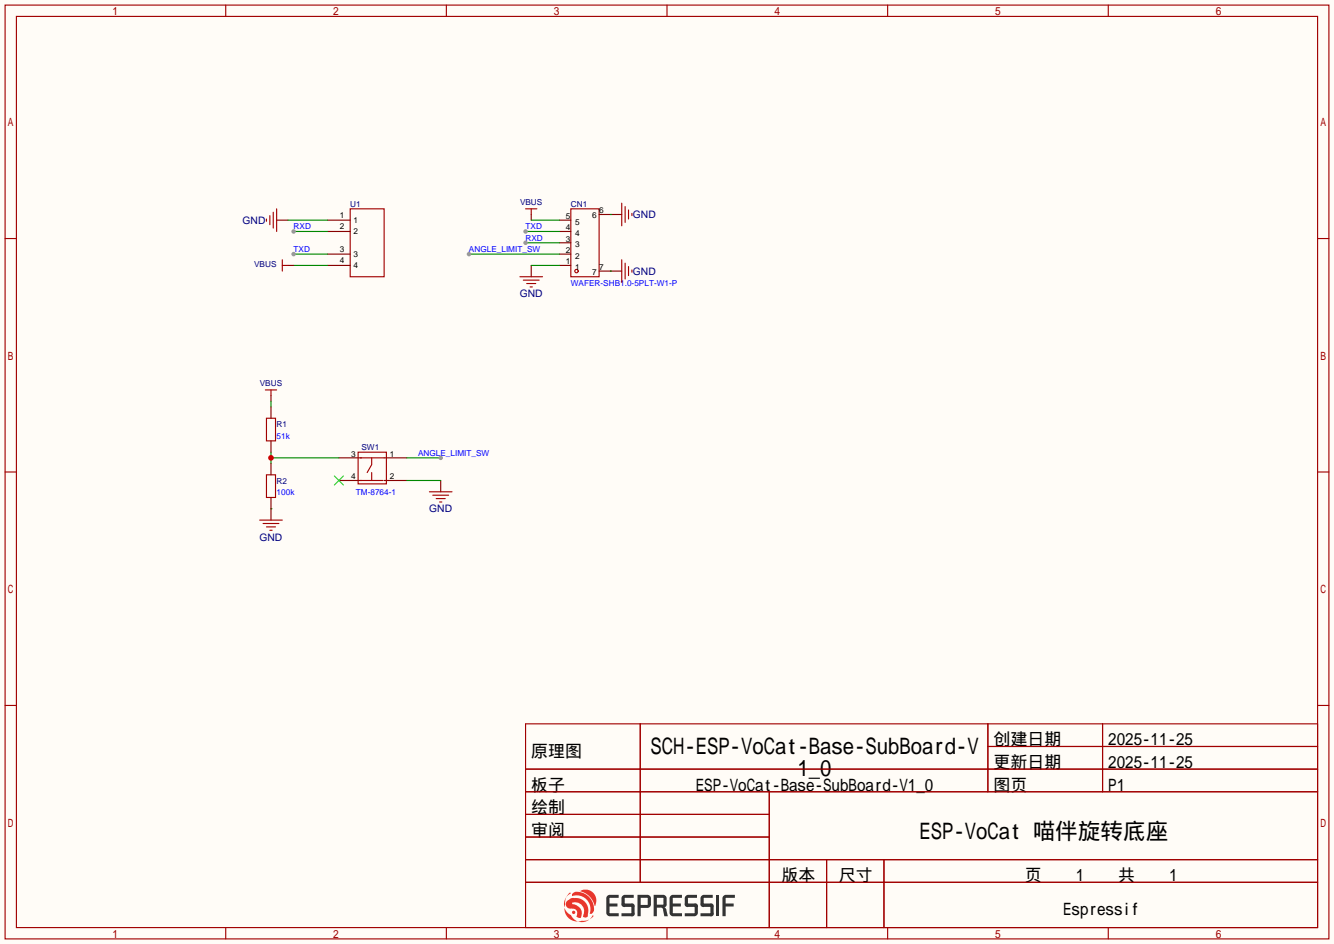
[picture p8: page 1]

原理图 | SCH-ESP-VoCat-Base-SubBoard-V 1_0 | 创建日期 | 2025-11-25

更新日期 | 2025-11-25

板子 | ESP-VoCat-Base-SubBoard-V1_0 | 图页 | P1
绘制 | | ESP-VoCat 喵伴旋转底座
审阅

Espressif

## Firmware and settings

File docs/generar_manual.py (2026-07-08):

#!/usr/bin/env python3
# -*- coding: utf-8 -*-
"""
================================================================================
 generar_manual.py
================================================================================
 Generador de plantilla PDF profesional tipo libro técnico.
 Utiliza exclusivamente ReportLab (Platypus + Canvas).

 Ejecución:
     python generar_manual.py

 Salida:
     Manual_Tecnico.pdf

 Autor  : [EDITAR] Tu Nombre
 Versión: 1.0.0
 Fecha  : Julio 2026
================================================================================
"""

# ==============================================================================
# IMPORTS
# ==============================================================================
import os
import sys
from datetime import datetime

from reportlab.lib import colors
from reportlab.lib.enums import TA_CENTER, TA_JUSTIFY, TA_LEFT, TA_RIGHT
from reportlab.lib.pagesizes import A4
from reportlab.lib.styles import ParagraphStyle, getSampleStyleSheet
from reportlab.lib.units import cm, mm
from reportlab.pdfbase import pdfmetrics
from reportlab.pdfbase.ttfonts import TTFont
from reportlab.pdfgen import canvas
from reportlab.platypus import (
    BaseDocTemplate,
    Frame,
    NextPageTemplate,
    PageBreak,
    PageTemplate,
    Paragraph,
    Spacer,
    Table,
    TableStyle,
)
from reportlab.platypus.flowables import Flowable


# ==============================================================================
# CONFIGURACIÓN GLOBAL DEL DOCUMENTO
#   → Modifica estas constantes para personalizar la plantilla.
# ==============================================================================

# --- Metadatos del documento (aparecen en propiedades del PDF) ---
DOC_TITLE    = "Manual Técnico ESP-VoCat"
DOC_SUBTITLE = "Sistema de Voz y Control para Mascotas con ESP32"
DOC_AUTHOR   = "[EDITAR] Nombre del Autor"
DOC_VERSION  = "1.0.0"
_MESES_ES = [
  "enero", "febrero", "marzo", "abril", "mayo", "junio",
  "julio", "agosto", "septiembre", "octubre", "noviembre", "diciembre",
]
_now = datetime.now()
DOC_DATE = f"{_now.day} de {_MESES_ES[_now.month - 1]} de {_now.year}"
DOC_SUBJECT  = "Documentación técnica del proyecto ESP-VoCat"
DOC_KEYWORDS = "ESP32, UART, sensores, motor paso a paso, IoT, firmware"

# --- Archivo de salida ---
OUTPUT_FILE = "Manual_Tecnico.pdf"

# --- Dimensiones de página ---
PAGE_WIDTH, PAGE_HEIGHT = A4          # 210 × 297 mm

# --- Márgenes profesionales ---
MARGIN_LEFT   = 2.5 * cm
MARGIN_RIGHT  = 2.5 * cm
MARGIN_TOP    = 3.0 * cm
MARGIN_BOTTOM = 2.5 * cm

# Área útil de contenido
CONTENT_WIDTH  = PAGE_WIDTH  - MARGIN_LEFT - MARGIN_RIGHT
CONTENT_HEIGHT = PAGE_HEIGHT - MARGIN_TOP  - MARGIN_BOTTOM


# ==============================================================================
# PALETA DE COLORES
#   → Colores sobrios para un aspecto técnico profesional.
# ==============================================================================
COLOR_PRIMARY    = colors.HexColor("#1A3A5C")   # Azul oscuro – títulos
COLOR_SECONDARY  = colors.HexColor("#2C6E9E")   # Azul medio  – subtítulos
COLOR_ACCENT     = colors.HexColor("#4A90D9")   # Azul claro  – acentos
COLOR_TEXT       = colors.HexColor("#2D2D2D")   # Gris oscuro – cuerpo
COLOR_LIGHT_TEXT = colors.HexColor("#666666")   # Gris medio  – pies de figura
COLOR_BORDER     = colors.HexColor("#B0BEC5")   # Gris claro  – bordes
COLOR_BG_LIGHT   = colors.HexColor("#F5F7FA")   # Fondo suave
COLOR_WHITE      = colors.white

# Colores de los cuadros informativos
COLOR_NOTE_BG      = colors.HexColor("#E8F4FD")   # Azul muy claro
COLOR_NOTE_BORDER  = colors.HexColor("#2196F3")   # Azul
COLOR_WARN_BG      = colors.HexColor("#FFF3E0")   # Naranja claro
COLOR_WARN_BORDER  = colors.HexColor("#FF9800")   # Naranja
COLOR_TIP_BG       = colors.HexColor("#E8F5E9")   # Verde claro
COLOR_TIP_BORDER   = colors.HexColor("#4CAF50")   # Verde

# Colores de tablas
COLOR_TABLE_HEADER = colors.HexColor("#1A3A5C")
COLOR_TABLE_ALT    = colors.HexColor("#EEF2F7")
COLOR_TABLE_BORDER = colors.HexColor("#90A4AE")


# ==============================================================================
# TIPOGRAFÍA
#   → Helvetica es la fuente estándar de ReportLab (no requiere registro).
# ==============================================================================
FONT_REGULAR = "Helvetica"
FONT_BOLD    = "Helvetica-Bold"
FONT_ITALIC  = "Helvetica-Oblique"
FONT_MONO    = "Courier"


# ==============================================================================
# CONTADOR GLOBAL DE FIGURAS
#   → Se incrementa automáticamente al crear cada placeholder de imagen.
# ==============================================================================
_figure_counter = 0


def next_figure_number():
    """Devuelve el siguiente número de figura y lo incrementa."""
    global _figure_counter
    _figure_counter += 1
    return _figure_counter


# ==============================================================================
# CLASE: ImagePlaceholder
#   → Caja con borde para insertar imágenes posteriormente.
#   → Reemplaza el contenido de esta clase por un Image() de ReportLab
#     cuando tengas la imagen lista.
# ==============================================================================
class ImagePlaceholder(Flowable):
  """
  Dibuja una caja rectangular con borde punteado y texto centrado.
  Úsala como marcador de posición para imágenes futuras.

  Parámetros:
      width, height : dimensiones de la caja
      label         : texto principal dentro de la caja
      sublabel      : texto secundario (instrucción)
  """

  def __init__(self, width, height, label="ESPACIO PARA IMAGEN",
               sublabel="Reemplazar por Imagen del Capítulo"):
    Flowable.__init__(self)
    self.width  = width
    self.height = height
    self.label  = label
    self.sublabel = sublabel

  def draw(self):
    canv = self.canv
    # Borde exterior
    canv.setStrokeColor(COLOR_BORDER)
    canv.setLineWidth(1.2)
    canv.setDash(6, 3)
    canv.rect(0, 0, self.width, self.height, stroke=1, fill=0)
    canv.setDash()  # Restaurar línea continua

    # Fondo suave
    canv.setFillColor(COLOR_BG_LIGHT)
    canv.rect(2, 2, self.width - 4, self.height - 4, stroke=0, fill=1)

    # Texto principal
    canv.setFillColor(COLOR_LIGHT_TEXT)
    canv.setFont(FONT_BOLD, 11)
    canv.drawCentredString(self.width / 2, self.height / 2 + 8, self.label)

    # Texto secundario
    canv.setFont(FONT_ITALIC, 9)
    canv.drawCentredString(self.width / 2, self.height / 2 - 10, self.sublabel)


# ==============================================================================
# CLASE: CoverImagePlaceholder
#   → Caja grande para la portada (reemplazar por imagen de portada).
# ==============================================================================
class CoverImagePlaceholder(Flowable):
  """Marcador de posición grande para la imagen de portada."""

  def __init__(self, width, height):
    Flowable.__init__(self)
    self.width  = width
    self.height = height

  def draw(self):
    canv = self.canv
    canv.setStrokeColor(COLOR_ACCENT)
    canv.setLineWidth(2)
    canv.setDash(8, 4)
    canv.rect(0, 0, self.width, self.height, stroke=1, fill=0)
    canv.setDash()

    canv.setFillColor(colors.HexColor("#EBF2FA"))
    canv.rect(3, 3, self.width - 6, self.height - 6, stroke=0, fill=1)

    canv.setFillColor(COLOR_SECONDARY)
    canv.setFont(FONT_BOLD, 16)
    canv.drawCentredString(self.width / 2, self.height / 2 + 6,
                           "ESPACIO PARA PORTADA")
    canv.setFont(FONT_ITALIC, 10)
    canv.setFillColor(COLOR_LIGHT_TEXT)
    canv.drawCentredString(self.width / 2, self.height / 2 - 14,
                           "Reemplazar por imagen de portada")


# ==============================================================================
# CLASE: CalloutBox
#   → Cuadros informativos: Nota, Advertencia, Consejo.
# ==============================================================================
class CalloutBox(Flowable):
  """
  Cuadro informativo con icono, título y cuerpo de texto.

  Parámetros:
      width, height : dimensiones
      title         : "Nota" | "Advertencia" | "Consejo"
      body          : texto del cuadro
      bg_color      : color de fondo
      border_color  : color del borde izquierdo
      icon          : símbolo unicode
  """

  def __init__(self, width, title, body, bg_color, border_color, icon="ℹ"):
    Flowable.__init__(self)
    self.box_width    = width
    self.title        = title
    self.body         = body
    self.bg_color     = bg_color
    self.border_color = border_color
    self.icon         = icon
    # Calcular altura dinámicamente según longitud del texto
    lines = max(2, len(body) // 80 + 1)
    self.height = 1.2 * cm + lines * 0.45 * cm

  def draw(self):
    canv = self.canv
    h = self.height
    w = self.box_width

    # Fondo
    canv.setFillColor(self.bg_color)
    canv.roundRect(0, 0, w, h, 4, stroke=0, fill=1)

    # Barra lateral de color
    canv.setFillColor(self.border_color)
    canv.rect(0, 0, 5, h, stroke=0, fill=1)

    # Título
    canv.setFillColor(self.border_color)
    canv.setFont(FONT_BOLD, 10)
    canv.drawString(14, h - 16, f"{self.icon}  {self.title}")

    # Cuerpo
    canv.setFillColor(COLOR_TEXT)
    canv.setFont(FONT_REGULAR, 9)
    # Dividir texto en líneas de ~90 caracteres
    words = self.body.split()
    line, lines_out = "", []
    for word in words:
      if len(line) + len(word) + 1 <= 90:
        line = (line + " " + word).strip()
      else:
        lines_out.append(line)
        line = word
    if line:
      lines_out.append(line)

    y = h - 30
    for ln in lines_out:
      canv.drawString(14, y, ln)
      y -= 13


# ==============================================================================
# CLASE: HorizontalRule
#   → Línea horizontal decorativa.
# ==============================================================================
class HorizontalRule(Flowable):
  """Línea horizontal de ancho configurable."""

  def __init__(self, width, thickness=0.5, color=COLOR_BORDER):
    Flowable.__init__(self)
    self.width     = width
    self.thickness = thickness
    self.color     = color
    self.height    = thickness + 4

  def draw(self):
    self.canv.setStrokeColor(self.color)
    self.canv.setLineWidth(self.thickness)
    self.canv.line(0, 2, self.width, 2)


# ==============================================================================
# CLASE: TOCItem
#   → Entrada del índice con puntos de relleno y número de página.
# ==============================================================================
class TOCItem(Flowable):
  """
  Línea del índice:  "1. Introducción .............. 5"
  """

  def __init__(self, number, title, page_num, width):
    Flowable.__init__(self)
    self.number   = number
    self.title    = title
    self.page_num = page_num
    self.width    = width
    self.height   = 18

  def draw(self):
    canv = self.canv
    left_text  = f"{self.number}. {self.title}"
    right_text = str(self.page_num)

    canv.setFont(FONT_REGULAR, 11)
    canv.setFillColor(COLOR_TEXT)
    canv.drawString(0, 4, left_text)

    canv.setFont(FONT_REGULAR, 11)
    text_width = canv.stringWidth(left_text, FONT_REGULAR, 11)
    page_width = canv.stringWidth(right_text, FONT_REGULAR, 11)
    dot_start = text_width + 8
    dot_end   = self.width - page_width - 4

    # Puntos de relleno
    canv.setFont(FONT_REGULAR, 8)
    canv.setFillColor(COLOR_LIGHT_TEXT)
    x = dot_start
    while x < dot_end:
      canv.drawString(x, 5, ".")
      x += 5

    # Número de página
    canv.setFont(FONT_REGULAR, 11)
    canv.setFillColor(COLOR_TEXT)
    canv.drawRightString(self.width, 4, right_text)


# ==============================================================================
# ESTILOS DE PÁRRAFO
#   → Centraliza todos los estilos tipográficos del documento.
# ==============================================================================
def build_styles():
  """
  Crea y devuelve un diccionario con todos los estilos del manual.
  Modifica tamaños, colores y espaciados aquí.
  """
  base = getSampleStyleSheet()

  styles = {}

  # --- Título principal (portada) ---
  styles["CoverTitle"] = ParagraphStyle(
    name="CoverTitle",
    fontName=FONT_BOLD,
    fontSize=28,
    leading=34,
    textColor=COLOR_PRIMARY,
    alignment=TA_CENTER,
    spaceAfter=12,
  )

  # --- Subtítulo (portada) ---
  styles["CoverSubtitle"] = ParagraphStyle(
    name="CoverSubtitle",
    fontName=FONT_REGULAR,
    fontSize=14,
    leading=18,
    textColor=COLOR_SECONDARY,
    alignment=TA_CENTER,
    spaceAfter=8,
  )

  # --- Metadatos de portada ---
  styles["CoverMeta"] = ParagraphStyle(
    name="CoverMeta",
    fontName=FONT_REGULAR,
    fontSize=11,
    leading=16,
    textColor=COLOR_LIGHT_TEXT,
    alignment=TA_CENTER,
    spaceAfter=4,
  )

  # --- Título de capítulo ---
  styles["ChapterTitle"] = ParagraphStyle(
    name="ChapterTitle",
    fontName=FONT_BOLD,
    fontSize=22,
    leading=28,
    textColor=COLOR_PRIMARY,
    spaceBefore=0,
    spaceAfter=16,
    borderWidth=0,
    borderPadding=0,
  )

  # --- Subcapítulo ---
  styles["SectionTitle"] = ParagraphStyle(
    name="SectionTitle",
    fontName=FONT_BOLD,
    fontSize=14,
    leading=18,
    textColor=COLOR_SECONDARY,
    spaceBefore=14,
    spaceAfter=8,
  )

  # --- Sub-subcapítulo ---
  styles["SubSectionTitle"] = ParagraphStyle(
    name="SubSectionTitle",
    fontName=FONT_BOLD,
    fontSize=12,
    leading=16,
    textColor=COLOR_ACCENT,
    spaceBefore=10,
    spaceAfter=6,
  )

  # --- Texto normal ---
  styles["BodyText"] = ParagraphStyle(
    name="BodyText",
    fontName=FONT_REGULAR,
    fontSize=10.5,
    leading=15,
    textColor=COLOR_TEXT,
    alignment=TA_JUSTIFY,
    spaceBefore=4,
    spaceAfter=8,
  )

  # --- Pie de figura ---
  styles["FigureCaption"] = ParagraphStyle(
    name="FigureCaption",
    fontName=FONT_ITALIC,
    fontSize=9,
    leading=12,
    textColor=COLOR_LIGHT_TEXT,
    alignment=TA_CENTER,
    spaceBefore=4,
    spaceAfter=16,
  )

  # --- Código / monospace ---
  styles["Code"] = ParagraphStyle(
    name="Code",
    fontName=FONT_MONO,
    fontSize=9,
    leading=13,
    textColor=colors.HexColor("#1B5E20"),
    backColor=colors.HexColor("#F1F8E9"),
    borderWidth=0.5,
    borderColor=colors.HexColor("#C8E6C9"),
    borderPadding=6,
    spaceBefore=6,
    spaceAfter=10,
    leftIndent=10,
  )

  # --- Título de tabla ---
  styles["TableTitle"] = ParagraphStyle(
    name="TableTitle",
    fontName=FONT_BOLD,
    fontSize=11,
    leading=14,
    textColor=COLOR_PRIMARY,
    spaceBefore=12,
    spaceAfter=6,
  )

  # --- Índice: título de sección ---
  styles["TOCTitle"] = ParagraphStyle(
    name="TOCTitle",
    fontName=FONT_BOLD,
    fontSize=20,
    leading=26,
    textColor=COLOR_PRIMARY,
    alignment=TA_CENTER,
    spaceAfter=24,
  )

  # --- Encabezado de página ---
  styles["Header"] = ParagraphStyle(
    name="Header",
    fontName=FONT_ITALIC,
    fontSize=8,
    textColor=COLOR_LIGHT_TEXT,
    alignment=TA_RIGHT,
  )

  # --- Pie de página ---
  styles["Footer"] = ParagraphStyle(
    name="Footer",
    fontName=FONT_REGULAR,
    fontSize=8,
    textColor=COLOR_LIGHT_TEXT,
    alignment=TA_CENTER,
  )

  return styles


# ==============================================================================
# CALLBACKS DE PÁGINA (encabezado y pie)
# ==============================================================================

def _draw_header_footer(canv, doc, is_cover=False):
  """
  Dibuja encabezado y pie de página en cada hoja.
  No se dibuja en la portada (is_cover=True).
  """
  canv.saveState()

  if not is_cover:
    # --- Encabezado ---
    canv.setFont(FONT_ITALIC, 8)
    canv.setFillColor(COLOR_LIGHT_TEXT)
    canv.drawString(MARGIN_LEFT, PAGE_HEIGHT - 1.6 * cm, DOC_TITLE)
    canv.drawRightString(PAGE_WIDTH - MARGIN_RIGHT, PAGE_HEIGHT - 1.6 * cm,
                         DOC_AUTHOR)
    # Línea bajo el encabezado
    canv.setStrokeColor(COLOR_BORDER)
    canv.setLineWidth(0.4)
    canv.line(MARGIN_LEFT, PAGE_HEIGHT - 1.8 * cm,
              PAGE_WIDTH - MARGIN_RIGHT, PAGE_HEIGHT - 1.8 * cm)

    # --- Pie de página ---
    canv.setFont(FONT_REGULAR, 8)
    canv.setFillColor(COLOR_LIGHT_TEXT)
    page_num = canv.getPageNumber()
    canv.drawCentredString(PAGE_WIDTH / 2, 1.2 * cm, f"— {page_num} —")
    canv.drawString(MARGIN_LEFT, 1.2 * cm, DOC_VERSION)
    canv.drawRightString(PAGE_WIDTH - MARGIN_RIGHT, 1.2 * cm, DOC_DATE)

    # Línea sobre el pie
    canv.setStrokeColor(COLOR_BORDER)
    canv.setLineWidth(0.4)
    canv.line(MARGIN_LEFT, 1.5 * cm,
              PAGE_WIDTH - MARGIN_RIGHT, 1.5 * cm)

  canv.restoreState()


def on_first_page(canv, doc):
  """Callback para la primera página (portada, sin encabezado)."""
  _draw_header_footer(canv, doc, is_cover=True)


def on_later_pages(canv, doc):
  """Callback para el resto de páginas."""
  _draw_header_footer(canv, doc, is_cover=False)


# ==============================================================================
# FUNCIONES AUXILIARES DE CONSTRUCCIÓN
# ==============================================================================

def make_callout_note(text, width):
  """Crea un cuadro de Nota."""
  return CalloutBox(width, "Nota", text,
                    COLOR_NOTE_BG, COLOR_NOTE_BORDER, icon="ℹ")


def make_callout_warning(text, width):
  """Crea un cuadro de Advertencia."""
  return CalloutBox(width, "Advertencia", text,
                    COLOR_WARN_BG, COLOR_WARN_BORDER, icon="⚠")


def make_callout_tip(text, width):
  """Crea un cuadro de Consejo."""
  return CalloutBox(width, "Consejo", text,
                    COLOR_TIP_BG, COLOR_TIP_BORDER, icon="✔")


def make_image_block(width, figure_desc, chapter_label=""):
  """
  Devuelve una lista de flowables: placeholder + pie de figura.
  Incrementa el contador global de figuras.
  """
  fig_num = next_figure_number()
  placeholder = ImagePlaceholder(
    width=width,
    height=7.5 * cm,
    label="ESPACIO PARA IMAGEN",
    sublabel=f"Reemplazar por Imagen del Capítulo{f' — {chapter_label}' if chapter_label else ''}",
  )
  caption = Paragraph(
    f"<b>Figura {fig_num}.</b> {figure_desc}",
    _STYLES["FigureCaption"],
  )
  return [placeholder, caption]


def make_table(title, headers, rows, col_widths=None):
  """
  Crea una tabla profesional con encabezado coloreado y filas alternas.

  Parámetros:
      title     : título sobre la tabla
      headers   : lista de strings (encabezados de columna)
      rows      : lista de listas (filas de datos)
      col_widths: anchos de columna (opcional, se calculan automáticamente)
  """
  elements = []
  elements.append(Paragraph(title, _STYLES["TableTitle"]))

  num_cols = len(headers)
  if col_widths is None:
    col_widths = [CONTENT_WIDTH / num_cols] * num_cols

  # Construir datos: encabezado + filas
  table_data = [headers] + rows

  tbl = Table(table_data, colWidths=col_widths, repeatRows=1)
  tbl.setStyle(TableStyle([
    # Encabezado
    ("BACKGROUND",    (0, 0), (-1, 0),  COLOR_TABLE_HEADER),
    ("TEXTCOLOR",     (0, 0), (-1, 0),  COLOR_WHITE),
    ("FONTNAME",      (0, 0), (-1, 0),  FONT_BOLD),
    ("FONTSIZE",      (0, 0), (-1, 0),  9),
    ("ALIGN",         (0, 0), (-1, 0),  "CENTER"),
    ("BOTTOMPADDING", (0, 0), (-1, 0),  8),
    ("TOPPADDING",    (0, 0), (-1, 0),  8),
    # Cuerpo
    ("FONTNAME",      (0, 1), (-1, -1), FONT_REGULAR),
    ("FONTSIZE",      (0, 1), (-1, -1), 9),
    ("ALIGN",         (0, 1), (-1, -1), "LEFT"),
    ("TOPPADDING",    (0, 1), (-1, -1), 6),
    ("BOTTOMPADDING", (0, 1), (-1, -1), 6),
    ("LEFTPADDING",   (0, 0), (-1, -1), 8),
    ("RIGHTPADDING",  (0, 0), (-1, -1), 8),
    # Filas alternas
    ("ROWBACKGROUNDS", (0, 1), (-1, -1),
     [COLOR_WHITE, COLOR_TABLE_ALT]),
    # Bordes
    ("GRID",          (0, 0), (-1, -1), 0.4, COLOR_TABLE_BORDER),
    ("BOX",           (0, 0), (-1, -1), 0.8, COLOR_TABLE_HEADER),
  ]))

  elements.append(tbl)
  elements.append(Spacer(1, 12))
  return elements


def make_chapter(number, title, body_text, figure_desc,
                 note_text, warn_text, tip_text,
                 extra_elements=None, chapter_label=""):
  """
  Construye el contenido completo de un capítulo.

  Parámetros:
      number          : número del capítulo (int)
      title           : título del capítulo
      body_text       : párrafo de ejemplo
      figure_desc     : descripción de la figura
      note_text       : texto del cuadro Nota
      warn_text       : texto del cuadro Advertencia
      tip_text        : texto del cuadro Consejo
      extra_elements  : lista adicional de flowables (tablas, código, etc.)
      chapter_label   : etiqueta para el placeholder de imagen
  """
  elements = []

  # Salto de página antes de cada capítulo
  elements.append(PageBreak())

  # Título del capítulo con número
  elements.append(Paragraph(
    f"Capítulo {number}<br/>{title}",
    _STYLES["ChapterTitle"],
  ))
  elements.append(HorizontalRule(CONTENT_WIDTH, thickness=1.5,
                                  color=COLOR_ACCENT))
  elements.append(Spacer(1, 10))

  # Párrafo de ejemplo
  elements.append(Paragraph(body_text, _STYLES["BodyText"]))

  # Placeholder de imagen + pie de figura
  elements.extend(make_image_block(CONTENT_WIDTH, figure_desc, chapter_label))

  elements.append(Spacer(1, 6))

  # Cuadros informativos
  elements.append(make_callout_note(note_text, CONTENT_WIDTH))
  elements.append(Spacer(1, 6))
  elements.append(make_callout_warning(warn_text, CONTENT_WIDTH))
  elements.append(Spacer(1, 6))
  elements.append(make_callout_tip(tip_text, CONTENT_WIDTH))

  # Elementos adicionales (tablas, código, subsecciones…)
  if extra_elements:
    elements.append(Spacer(1, 10))
    elements.extend(extra_elements)

  return elements
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
